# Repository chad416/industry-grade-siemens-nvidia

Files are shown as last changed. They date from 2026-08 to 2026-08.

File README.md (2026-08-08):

# FC01 Siemens/NVIDIA compact filling cell - Revision G

> FICTIONAL ENGINEERING PROJECT - NOT FOR CONSTRUCTION.

> CONCEPTUAL SAFETY ARCHITECTURE - REQUIRES PROJECT-SPECIFIC RISK ASSESSMENT, DESIGN, VERIFICATION AND VALIDATION BY A QUALIFIED MACHINERY-SAFETY ENGINEER. NO PERFORMANCE LEVEL, SIL, CATEGORY, CE/UKCA CONFORMITY OR REGULATORY COMPLIANCE IS CLAIMED.

Revision G is an evidence-driven execution release candidate. It preserves the verified Revision-F PLC/AI, QET and FreeCAD baseline while adding a disabled-by-default secure cloud foundation, exact Siemens native-access handoff, current NVIDIA execution pipeline, and commissioning-ready blank records.

Supported description: **cloud-ready and native-execution-ready with software-only NVIDIA pipeline validation**. Native TIA/WinCC/Startdrive/PLCSIM compile, representative data/model/target runtime, site electrical calculations, physical FAT/SAT/commissioning and qualified safety/electrical review remain open exactly as recorded in `00_project_control/revision_g_gate_status.md`.

No cloud resources were created. The PLC remains authoritative; NVIDIA is non-safety and any missing, stale, malformed, contradictory, uncertain or low-confidence result holds product and never commands hazardous outputs.

THE NVIDIA VISION SUBSYSTEM IS NON-SAFETY-RELATED AND MUST NOT BE USED AS THE SOLE MEANS OF PERSONNEL PROTECTION, SAFE STOP, GUARD MONITORING OR HAZARDOUS-MOTION CONTROL.

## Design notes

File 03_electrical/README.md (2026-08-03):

# Electrical design boundary - Revision E

> FICTIONAL ENGINEERING PROJECT — NOT FOR CONSTRUCTION

> CONCEPTUAL SAFETY ARCHITECTURE — REQUIRES PROJECT-SPECIFIC RISK ASSESSMENT, DESIGN, VERIFICATION AND VALIDATION BY A QUALIFIED MACHINERY-SAFETY ENGINEER. NO PERFORMANCE LEVEL, SIL, CATEGORY, CE CONFORMITY OR REGULATORY COMPLIANCE IS CLAIMED.

The controlled `revision_e` directory contains a genuinely authored, deterministic 26-folio QElectroTech 0.100 project reconciled at source level to the Revision-E device, I/O, terminal, cable and network schedules. Static verification covers folio structure, embedded symbols/conductors, unique PLC addresses, terminals and cables, scheduled device coverage and page-boundary constraints. The historical Revision-A project remains quarantined under `native_baseline` and is not the current schematic package.

The exact corrected QET SHA-256 was not reopened and exported after the final layout corrections. Native cross-reference resolution, final-hash PDF export and visual review of all 26 final folios therefore remain blocked. Site power/earthing/fault-current data, conductor sizing, protection/coordination, final vendor metadata and qualified construction review also remain open; no construction schematic claim is made.

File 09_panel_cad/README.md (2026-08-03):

# Panel CAD boundary - Revision E

> FICTIONAL ENGINEERING PROJECT — NOT FOR CONSTRUCTION

> CONCEPTUAL SAFETY ARCHITECTURE — REQUIRES PROJECT-SPECIFIC RISK ASSESSMENT, DESIGN, VERIFICATION AND VALIDATION BY A QUALIFIED MACHINERY-SAFETY ENGINEER. NO PERFORMANCE LEVEL, SIL, CATEGORY, CE CONFORMITY OR REGULATORY COMPLIANCE IS CLAIMED.

Revision E replaces the historical panel baseline as the current engineering representation. The controlled `revision_e` directory contains a genuine FreeCAD 1.1.3 selected-architecture assembly, native reopen/shape evidence, STEP and IGES reimport evidence, a structurally verified DXF mounting plate, schedules, dimensioned PDFs and four major rendered views. The historical Revision-A native files remain quarantined under `native_baseline` and are not evidence for Revision E.

The native verification record passes the dimensional and exchange checks stated there. It does not authorize fabrication. Final enclosure/IP selection, protective devices, terminal and relay families, NVIDIA carrier/cooling, vendor drilling and clearances, cable entry, duct fill, thermal rise, PE/bonding, EMC, site short-circuit data and qualified-human construction review remain open.

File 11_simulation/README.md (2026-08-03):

# Deterministic controls-process simulation

> FICTIONAL ENGINEERING PROJECT — NOT FOR CONSTRUCTION

This directory contains an independent, deterministic Python verification model for the compact two-nozzle filling cell. It is not a Siemens PLC application, TIA Portal compile, PLCSIM run, validated fluid model, or physical commissioning record.

## Model boundary

`filling_cell_simulator.py` couples four explicit time-stepped models:

- A controller state machine with command arbitration, first-out diagnostics, quality holding, reset/start separation, and restart inhibition.
- A plant with bottle transport, gate/clamp travel, common pump ramp, independent fail-closed valves, pulse totals, analog flow, and physical fill volume.
- A vision endpoint implementing monotonic inspection IDs, ready/busy/result timing, result correlation, heartbeat supervision, and semantic result validation.
- A capper endpoint implementing ready/request/busy/complete/fault timing.

The default integration step is 20 ms. The simulated controller observes only field and interface signals. Physical volume is hidden plant state used by the simulated vision endpoint, allowing correlated meter-calibration faults to produce independent underfill/overfill quality results.

## Deterministic failure behavior

All faults are injected into the evolving model, not returned from a result lookup. Timed/state-dependent injections cover bottle sensing, gate/clamp motion, VFDs, air/product utilities, pulse and analog disagreement, valve feedback, HMI communication, power, capper handshaking, PLC/vision heartbeats, result timeout, stale inspection ID, low confidence, and bottle quality failure.

The following invariants are checked at every step:

- No pump command outside `FILLING`.
- No valve command without the common pump command.
- No conveyor command while clamp/filling commands are active.
- No energized motion/fill command while simulated power is absent.
- Gate and clamp feedback remain proven through filling, settle, and inspection.
- Release occurs only after the capper complete handshake.
- Recovery/reset does not synthesize a start edge.

## Run and inspect

From the project root:

```powershell
python -m unittest discover -s 11_simulation/tests -v
python 11_simulation/run_scenarios.py
```

The scenario runner writes:

- `outputs/scenario_results.csv`: one evidence summary per canonical scenario.
- `outputs/traces/<scenario>.csv`: every sampled state, command, feedback, flow, interface, and handshake value.
- `outputs/run_metadata.json`: time-step configuration and an explicit `native_plcsim = NOT RUN` limitation.

Tests include deterministic repeatability, a 10/20/40/50 ms integration-step sweep, a supported 400/500/700 ml recipe-target sweep, transition-order checks, channel-independent shutoff, restart-inhibition checks, and negative PLC–vision protocol cases.

## Truthfulness limitation

Passing these tests demonstrates consistency of this independent model and its declared properties only. It does not prove that the Siemens sources compile, execute equivalently, meet PLC scan-time constraints, or pass PLCSIM/native hardware tests. Those gates remain separate and incomplete until the native Siemens toolchain is used.

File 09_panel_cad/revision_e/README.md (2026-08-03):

# FC01 Revision-E native panel CAD

> FICTIONAL ENGINEERING PROJECT — NOT FOR CONSTRUCTION

> CONCEPTUAL SAFETY ARCHITECTURE — REQUIRES PROJECT-SPECIFIC RISK ASSESSMENT, DESIGN, VERIFICATION AND VALIDATION BY A QUALIFIED MACHINERY-SAFETY ENGINEER. NO PERFORMANCE LEVEL, SIL, CATEGORY, CE CONFORMITY OR REGULATORY COMPLIANCE IS CLAIMED.

This directory is the genuine Revision-E FreeCAD package built and reopened with the controlled portable FreeCAD 1.1.3 command-line executable. It does not replace the quarantined Revision-A baseline in `../native_baseline`.

## Native boundary

- `FC01_control_panel_revision_e.FCStd` is the authoritative native model.
- STEP and IGES are full-panel physical-shape exports; non-physical clearance/segregation volumes are excluded. Independent native verification confirms STEP solid retention and a valid IGES face-compound/envelope; IGES solid retention is not claimed.
- `FC01_mounting_plate_revision_e.dxf` is a FreeCAD-exported local-coordinate mounting-plate outline and hole pattern.
- The placement and hole schedules distinguish selected manufacturer envelopes from provisional and architecture-only assumptions.
- The four PNGs are genuine FreeCAD GUI views rendered from the same physical geometry-definition source before a rejected post-save generic ZIP-repack attempt. A later controlled correction changed only the SW100/FW100/PC200 side-clearance metadata and its dimension-basis text; x/y/z/width/height/depth geometry and mounting holes did not change. The headless build requires the exact controlled PNG hashes and an invariant physical-geometry fingerprint. No final FCStd byte identity or second GUI reopen is claimed.
- General-arrangement and mounting-plate PDFs use those genuine views plus the final controlled geometry/schedules.

## Reproduction

Run the headless generator with isolated FreeCAD configuration files, then run the independent command-line verification in a second process:

```powershell
& $env:FC01_FREECAD_CMD -u $env:FC01_FREECAD_USER_CFG -s $env:FC01_FREECAD_SYSTEM_CFG scripts/freecad_revision_e.py
& $env:FC01_FREECAD_CMD -u $env:FC01_FREECAD_VERIFY_USER_CFG -s $env:FC01_FREECAD_VERIFY_SYSTEM_CFG scripts/verify_freecad_revision_e.py
```

The model is not a supplier-approved production model. The enclosure, protection, PSU, relay, terminal, duct, PE, Jetson carrier and cooling solution remain selection-dependent. Drive mounting coordinates require final confirmation against order-number CAx before drilling. Site supply, fault current, thermal environment, cable routes, maintenance access and qualified safety work remain external gates.

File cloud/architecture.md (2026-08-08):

# Revision G secure execution architecture

> FICTIONAL ENGINEERING PROJECT - NOT FOR CONSTRUCTION.

> CONCEPTUAL SAFETY ARCHITECTURE - REQUIRES PROJECT-SPECIFIC RISK ASSESSMENT, DESIGN, VERIFICATION AND VALIDATION BY A QUALIFIED MACHINERY-SAFETY ENGINEER. NO PERFORMANCE LEVEL, SIL, CATEGORY, CE/UKCA CONFORMITY OR REGULATORY COMPLIANCE IS CLAIMED.

Two laboratory environments are separated from each other and from any plant/OT network.

## Environment A - Siemens engineering

A Windows engineering host provides TIA Portal V20, STEP 7 Professional, WinCC Unified, Startdrive, PLCSIM/PLCSIM Advanced and TIA Openness. The primary recommendation is a dedicated always-on engineering workstation or a Siemens-supported VMware/Hyper-V environment. Ordinary Google Compute Engine is retained only as a technically plausible **unsupported laboratory candidate** pending written Siemens confirmation; Siemens V20 installation documentation explicitly names VMware vSphere 8+, Workstation/Player 17+ and Hyper-V Server 2019+, not GCE.

## Environment B - NVIDIA engineering

A separate Ubuntu 24.04 GPU host is provisioned only after approval. DeepStream 9.1 currently requires Ubuntu 24.04, driver 595.58.03, CUDA 13.2 and TensorRT 10.16.0.72 on dGPU. A G2/L4-class VM is a capacity and price candidate, not a selected or provisioned target. Jetson deployment must use the exact DeepStream/JetPack platform matrix and regenerate TensorRT engines for the intended runtime/hardware.

## Network and evidence flow

- Dedicated VPC/subnet; no VM external IP.
- IAP TCP forwarding is the only administrative ingress; firewall source is `35.235.240.0/20` to RDP/SSH tags.
- Cloud NAT provides bounded installation egress; egress firewall permits DNS, NTP and TLS only.
- Separate keyless service accounts; no project-owner grants.
- Versioned, uniform-access, public-access-prevented evidence bucket; no secrets in objects or Terraform state.
- Project audit logging plus optional CPU alert policies; notification-channel IDs remain operator-supplied variables.
- OPC UA and PLC traffic are laboratory-only. No direct conduit to a real plant is created.

Official sources:

- https://support.industry.siemens.com/cs/attachments/109963850/Install_STEP7_WinCC_V20_enUS.pdf
- https://cloud.google.com/iap/docs/tcp-forwarding-overview
- https://cloud.google.com/compute/docs/instances/schedule-instance-start-stop
- https://docs.nvidia.com/metropolis/deepstream/dev-guide/text/DS_Installation.html

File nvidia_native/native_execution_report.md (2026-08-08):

# NVIDIA native execution report

> FICTIONAL ENGINEERING PROJECT - NOT FOR CONSTRUCTION.

> CONCEPTUAL SAFETY ARCHITECTURE - REQUIRES PROJECT-SPECIFIC RISK ASSESSMENT, DESIGN, VERIFICATION AND VALIDATION BY A QUALIFIED MACHINERY-SAFETY ENGINEER. NO PERFORMANCE LEVEL, SIL, CATEGORY, CE/UKCA CONFORMITY OR REGULATORY COMPLIANCE IS CLAIMED.

The local RTX 5060 driver query executed successfully. CUDA toolkit (`nvcc`), Docker, NVIDIA Container Toolkit, TAO, TensorRT, DeepStream, OpenUSD and Omniverse were not found. No cloud GPU resource exists. The deterministic synthetic smoke exercises the existing acquisition/preprocess/mock boundary and proves the mock backend is refused by `VisionService`; it does not decode representative images, train a model, create ONNX/TensorRT artifacts, measure latency or validate production OPC UA.

Current official planning baseline is DeepStream 9.1 on Ubuntu 24.04; dGPU prerequisites include driver 595.58.03, CUDA 13.2 and TensorRT 10.16.0.72. TAO-trained engines must be regenerated for their exact TensorRT/CUDA/hardware environment. Sources: https://docs.nvidia.com/metropolis/deepstream/dev-guide/text/DS_Installation.html and https://docs.nvidia.com/tao/tao-toolkit/latest/text/ds_tao/deepstream_tao_integration.html.

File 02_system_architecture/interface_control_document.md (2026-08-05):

# PLC-NVIDIA interface control document - Revision F

> FICTIONAL ENGINEERING PROJECT — NOT FOR CONSTRUCTION

> CONCEPTUAL SAFETY ARCHITECTURE — REQUIRES PROJECT-SPECIFIC RISK ASSESSMENT, DESIGN, VERIFICATION AND VALIDATION BY A QUALIFIED MACHINERY-SAFETY ENGINEER. NO PERFORMANCE LEVEL, SIL, CATEGORY, CE CONFORMITY OR REGULATORY COMPLIANCE IS CLAIMED.

## Ownership and transaction

The PLC freezes session epoch, inspection ID, recipe, bottle count, fill target and expected model/dataset/calibration identities before raising the level-held request. The edge validates the complete snapshot, publishes capture acknowledgement and processing state, then writes one complete immutable result before `RESULT_VALID`. The PLC accepts only the exact current session/ID, coherent capture acknowledgement, healthy service/camera/model, approved identities, allowed disposition/reasons/confidence and PLC-derived age. Exact acknowledgement clears the result but never authorizes transfer.

The 47 typed nodes, OPC UA types, owner, update rule and invalid action are controlled in `10_schedules/nvidia_interface_tags.csv`. OPC UA typed scalars abstract byte order; no application byte swapping is permitted. Disconnect, restart, recipe change, clock jump, stale/duplicate/future ID, malformed/contradictory payload, low confidence, fault, queue saturation or maintenance state fails closed.

THE NVIDIA VISION SUBSYSTEM IS NON-SAFETY-RELATED AND MUST NOT BE USED AS THE SOLE MEANS OF PERSONNEL PROTECTION, SAFE STOP, GUARD MONITORING OR HAZARDOUS-MOTION CONTROL.

Local encrypted asyncua tests are not production S7/Jetson/PKI evidence. Native TIA/WinCC compilation and target endpoint commissioning remain blocked.

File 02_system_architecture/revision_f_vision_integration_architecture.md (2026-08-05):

# Revision-F NVIDIA vision integration architecture

> FICTIONAL ENGINEERING PROJECT - NOT FOR CONSTRUCTION

> CONCEPTUAL SAFETY ARCHITECTURE - REQUIRES PROJECT-SPECIFIC RISK ASSESSMENT, DESIGN, VERIFICATION AND VALIDATION BY A QUALIFIED MACHINERY-SAFETY ENGINEER. NO PERFORMANCE LEVEL, SIL, CATEGORY, CE CONFORMITY OR REGULATORY COMPLIANCE IS CLAIMED.

> THE NVIDIA VISION SUBSYSTEM IS NON-SAFETY-RELATED AND MUST NOT BE USED AS THE SOLE MEANS OF PERSONNEL PROTECTION, SAFE STOP, GUARD MONITORING OR HAZARDOUS-MOTION CONTROL.

## Functional boundary

The Siemens S7-1500 remains the sole owner of modes, sequence state, interlocks, timeouts, actuator and drive requests, restart behavior, product disposition and transfer permission. Process flow and level instrumentation remains the deterministic fill measurement. Vision supplies an independent quality observation only: bottle presence/alignment, visible fill band, underfill/overfill indication, severe foam or abnormal appearance and visible spill/leak where optics permit.

The provisional model approach is hybrid rather than generic object detection alone:

1. deterministic geometry and calibration locate the carrier, bottle ROIs and fill-reference band;
2. segmentation or calibrated level-line estimation measures visible liquid/foam regions;
3. detection localizes bottle/nozzle/spill anomalies where a global classifier would obscure cause;
4. a learned classifier or Visual ChangeNet-style comparison may provide an additional anomaly score against approved reference images;
5. the edge policy combines the observations conservatively and publishes PASS only when every required channel is present, coherent and above validated thresholds.

This approach is provisional until transparent-container feasibility, glare, liquid appearance, production variation and reject economics are measured.

## One-camera versus two-camera decision

| Criterion | One camera | Two cameras |
|---|---|---|
| Initial cost and integration | Lower | Higher |
| Two-bottle coverage | Possible with wider field and lower pixels/mm | Dedicated or overlapping views improve per-bottle resolution |
| Occlusion and parallax | Higher risk | Lower risk when views are selected independently |
| Glare management | One illumination/view compromise | More options for cross-polarized/backlight and oblique views |
| Calibration/maintenance | Simpler | Additional calibration, synchronization and spares |
| Current disposition | Provisional baseline for feasibility trial | Contingency if pixel, glare or occlusion margin fails |

No camera count, sensor, lens or enclosure is released for procurement. The optical feasibility trial must calculate field of view and pixels per smallest decision feature, then demonstrate focus, distortion, exposure and motion-blur margin at maximum line speed.

## Trigger and timing lifecycle

The PLC freezes recipe, carrier position, expected bottle count, target fill band, expected model/dataset/calibration identities and the nonzero session/inspection identity before asserting a level-held trigger. The edge publishes capture acknowledgement only after the correct request identity is accepted and an image is bound to it. Processing state then advances through acquired, preprocessing, inference and post-processing. Result payload fields are written first and `RESULT_VALID` last. The immutable publication remains until exact PLC acknowledgement.

Any timeout, heartbeat loss/regression, stale/duplicate/future identity, recipe mutation, clock discontinuity, camera/model/configuration fault, queue saturation, malformed or contradictory payload, insufficient confidence or expired result prevents PASS. Recovery never restarts the machine automatically.

## Failure containment

- The edge has no writable PLC node that energizes motion or bypasses a permissive.
- The PLC decommands pump and fill valves independently of vision communications.
- Offline buffering of inspection decisions is prohibited. At most one current immutable unacknowledged publication may be restored after restart.
- Log-storage failure is a blocking diagnostic because required traceability cannot be completed.
- Maintenance bypass is a request for controlled operator disposition, not an automatic quality acceptance.
- A recipe or calibration change invalidates an active transaction and requires a new inspection.

## Network and trust boundary

`-PC200` resides in VLAN 20 and acts as the OPC UA client to the PLC server in VLAN 10 through the deny-by-default `-FW100` boundary. Only TCP 4840 for the named application identities and approved namespace is permitted. Application and user certificates, pinned server identity, trust/revocation stores, least-privilege node rights, authenticated time and centralized security logging are required. Image transfer is not permitted across the PLC boundary.

## Time and records

The PLC correlation identity is authoritative even if clocks disagree. UTC capture and inference timestamps support diagnostics and result-age checks but never replace session/inspection correlation. The site must provide an authenticated NTP/PTP hierarchy, maximum permitted clock step, resynchronization rule and log-retention owner. Raw images are not retained by default; approved fault/challenge samples may be retained under a documented privacy, capacity and deletion policy.

## Maintainability

Camera, lens, lighting, carrier, edge image, model bundle, dataset baseline and calibration each have independent identifiers and hashes. Replacement requires mechanical datum restoration, focus/aperture lock, exposure/illumination verification, calibration challenge images, secure OPC UA smoke tests and a bounded rollback. A golden configuration alone is not proof that optics or process conditions remain acceptable.

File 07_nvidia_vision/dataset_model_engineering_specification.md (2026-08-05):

# FC01 dataset and model engineering specification

> FICTIONAL ENGINEERING PROJECT — NOT FOR CONSTRUCTION

> CONCEPTUAL SAFETY ARCHITECTURE — REQUIRES PROJECT-SPECIFIC RISK ASSESSMENT, DESIGN, VERIFICATION AND VALIDATION BY A QUALIFIED MACHINERY-SAFETY ENGINEER. NO PERFORMANCE LEVEL, SIL, CATEGORY, CE CONFORMITY OR REGULATORY COMPLIANCE IS CLAIMED.

No representative dataset, trained model, accuracy result or production threshold is delivered. Synthetic data is permitted only for pipeline tests and is never production validation evidence.

## Inspection strategy

The provisional architecture is hybrid: calibrated deterministic geometry estimates visible fill line and alignment inside verified bottle ROIs; a detector/segmenter localizes bottles, liquid/foam and visible spill evidence. This is more defensible than a single global pass/fail classifier because it preserves interpretable geometry and defect localization. Transparent bottles, specular glare and foam require polarized/diffuse lighting trials. Cap inspection is a downstream extension, not part of the released filling decision.

## Required collection matrix

Collect by independent production lot and acquisition session across every bottle SKU, nominal/under/over fill, liquid color/transmission/viscosity, foam severity, bottle lot, lighting drift, camera/lens replacement, focus and exposure limits, background, nozzle position, misalignment, occlusion, contamination, drip/spill, empty carrier, label state and environmental condition. Record true fill reference by a traceable independent method. Include clean negatives and hard negatives. Do not manufacture class balance by duplicating adjacent video frames.

## Storage and annotation

The dataset root contains `images/`, `annotations/`, `manifests/`, `calibration/`, `collection_records/` and `reviews/`. `dataset_manifest.csv` uses the exact v2 header enforced by `dataset_tool.py`; all paths are dataset-root-relative and every image/annotation has SHA-256. Production lot plus acquisition session is the leakage-control group. Real/synthetic provenance is mandatory.

Classes: bottle; bottle misalignment; visible bottle damage; liquid region; foam; drip; spill. Each bottle has a polygon/bounding box and two calibrated fill-line endpoints where visible. Occluded or ambiguous samples use `unknown`, never a forced pass/fail label. Two reviewers independently review release test/challenge data; disagreements are adjudicated by an authorized domain reviewer and the original labels are retained in history.

`dataset_tool.py validate` verifies schema, paths, hashes, exact duplicates, review state and split leakage. `split` makes a deterministic group-level assignment. Exact SHA duplicates are implemented; near-duplicate image embedding/perceptual review remains a required external extension once images exist.

## Evaluation and promotion

Freeze train/validation/test manifests before threshold selection. Select thresholds on validation only; run the held-out test once for the candidate. Report per-class precision, recall and F1, confusion matrices, under/overfill error against the physical reference, false accept and false reject by condition, calibration error, robustness slices and confidence coverage. `dataset_tool.py evaluate` computes binary confusion/false-accept/false-reject values from supplied predictions; unit-test rows are not performance evidence.

Model promotion requires: controlled model/framework/container/config/dataset/calibration hashes; independent test and challenge-set review; target camera-to-PLC latency distribution; thermal and reconnect soak; failure-mode test; cybersecurity review; named approval authority; rollback rehearsal; and PLC/HMI acceptance criteria. A signed bundle includes model, input/output tensor contract, preprocessing, class map, thresholds, dataset ID, calibration compatibility, SBOM and model card. Rollback disables production, restores the prior complete bundle, verifies hashes, repeats negative tests and never automatically restarts the machine.

## External closure criteria

Provide representative real images and traceable fill references; select camera/lens/light and target edge; approve privacy/retention; run collection and independent annotation; install a supported training/runtime stack; execute training/evaluation; and retain immutable logs/hashes. Only those results may populate `model_card.md` and `evaluation_report.md`.

THE NVIDIA VISION SUBSYSTEM IS NON-SAFETY-RELATED AND MUST NOT BE USED AS THE SOLE MEANS OF PERSONNEL PROTECTION, SAFE STOP, GUARD MONITORING OR HAZARDOUS-MOTION CONTROL.

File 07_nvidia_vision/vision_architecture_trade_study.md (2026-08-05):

# FC01 vision architecture and provisional hardware trade study

> FICTIONAL ENGINEERING PROJECT — NOT FOR CONSTRUCTION

> CONCEPTUAL SAFETY ARCHITECTURE — REQUIRES PROJECT-SPECIFIC RISK ASSESSMENT, DESIGN, VERIFICATION AND VALIDATION BY A QUALIFIED MACHINERY-SAFETY ENGINEER. NO PERFORMANCE LEVEL, SIL, CATEGORY, CE CONFORMITY OR REGULATORY COMPLIANCE IS CLAIMED.

No camera, lens, lighting or edge computer is selected. Dimensions, watts and thermal values remain controlled input fields until throughput, bottle envelope, environment and vendor data exist.

## Inspection requirement

The primary station verifies two-bottle presence/alignment, visible fill level, underfill/overfill, severe foam and visible spill/leak evidence where geometry permits. Flow and level instrumentation remain the deterministic filling-process measurements. Vision is an independent non-safety quality check. Cap inspection is downstream scope.

## One versus two cameras

| Criterion | One paired-bottle camera | Two bottle cameras |
|---|---|---|
| Cost, ports, power, calibration | Lower | Higher |
| Pixels per bottle and independent adjustment | Lower/shared | Higher/independent |
| Occlusion and nozzle accommodation | Harder | Easier |
| Common-cause camera failure | Both observations lost | Partial diagnostic availability, but cell still HOLDs unless the approved recipe permits otherwise |
| Maintenance | One spare/alignment | More spares and cross-camera consistency |

The provisional baseline is one fixed global-shutter color camera with a paired-bottle field of view, backlight for liquid boundary and separately controlled diffuse front light for gross visible defects/spill. Select two cameras if the measured pixel density, occlusion or depth-of-field trial fails. This decision cannot close without bottle/nozzle envelope and physical images.

## Optical calculations and timing

Required field width is `2 × maximum bottle width + centre spacing allowance + setup margins`, then at least 10% framing reserve. Pixel density is `horizontal pixels / calibrated field width`; validation must establish the minimum pixels needed for fill tolerance and defect dimensions. Thin-lens first estimate is `f ≈ sensor width × working distance / field width`; confirm with manufacturer lens data and working-distance trial.

The PLC freezes the indexed carrier, allows drip/foam settle, and raises the inspection request. Capture acknowledgement must match the request ID before processing. Exposure must limit blur to the validated pixel budget: `blur_px = image_velocity_mm_s × exposure_s × pixel_density_px_mm`. Record trigger jitter, exposure start, capture, processing and publication timing. Edge UTC timestamps are diagnostic only; PLC result-age acceptance uses the PLC monotonic/receipt clock.

## Edge platform criteria

| Criterion | Jetson Orin industrial module/carrier | Industrial x86 with NVIDIA GPU |
|---|---|---|
| Compactness/power | Usually favorable | Usually larger/higher |
| Service ecosystem | Embedded Linux/vendor carrier specific | Conventional industrial-PC service |
| GPU/runtime portability | JetPack/DeepStream constrained | Broader discrete-GPU options |
| Expansion/storage | Carrier dependent | Often broader |
| Lifecycle/environment | Requires selected industrial carrier evidence | Requires selected industrial PC/GPU evidence |

Selection requires measured camera rate, model memory/compute, worst-case latency, ambient/enclosure temperature, ingress/vibration, supply, lifecycle, cybersecurity support and spares strategy. Reserve separately protected power, service isolation, Ethernet switch port, grounded metal mounting, shield termination, cable entries, ventilation/heat allowance and maintenance clearance. The current panel allocation is provisional; no wattage or clearance is released from this trade study.

Network design uses the managed OT switch, one edge-to-PLC OPC UA conduit and separately governed maintenance access. Time uses the site NTP/PTP hierarchy with offset alarms; transaction correctness never depends solely on wall-clock agreement. Configuration/model/calibration are immutable bundles with hashes. Replacement requires identical or reviewed hardware, restored trust/config, new optical calibration where the imaging chain changes, negative tests and no automatic machine restart.

THE NVIDIA VISION SUBSYSTEM IS NON-SAFETY-RELATED AND MUST NOT BE USED AS THE SOLE MEANS OF PERSONNEL PROTECTION, SAFE STOP, GUARD MONITORING OR HAZARDOUS-MOTION CONTROL.

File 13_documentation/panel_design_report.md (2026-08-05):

# Panel design report - Revision F

> FICTIONAL ENGINEERING PROJECT — NOT FOR CONSTRUCTION

> CONCEPTUAL SAFETY ARCHITECTURE — REQUIRES PROJECT-SPECIFIC RISK ASSESSMENT, DESIGN, VERIFICATION AND VALIDATION BY A QUALIFIED MACHINERY-SAFETY ENGINEER. NO PERFORMANCE LEVEL, SIL, CATEGORY, CE CONFORMITY OR REGULATORY COMPLIANCE IS CLAIMED.

## Native layout basis

The inherited Revision-E FreeCAD 1.1.3 selected-architecture assembly remains the current natively reopened CAD authority: 800 x 800 x 300 mm provisional enclosure, drilled mounting plate, separated drive/power/control/network zones, Siemens PLC/I/O/HMI/drive envelopes and a provisional NVIDIA edge-compute envelope.

## Revision-F electrical delta boundary

`03_electrical/revision_f_nvidia_electrical_delta.md` reserves provisional protected edge, camera, lighting and service branches plus unique C200-C206 power/network cable identifiers. It is a standalone delta and has not been incorporated into the native FCStd, QET, canonical BOM, terminal/cable/P2P or panel-placement authorities. Gate 14 therefore remains PARTIAL.

## Open construction inputs

Selected carrier/camera/light hardware, enclosure series/IP, branch protection, cable entry, duct fill, thermal rise, PE/bonding, EMC, fault-current/SCCR data, vendor drilling, site clearances and qualified-human review remain open.

THE NVIDIA VISION SUBSYSTEM IS NON-SAFETY-RELATED AND MUST NOT BE USED AS THE SOLE MEANS OF PERSONNEL PROTECTION, SAFE STOP, GUARD MONITORING OR HAZARDOUS-MOTION CONTROL.

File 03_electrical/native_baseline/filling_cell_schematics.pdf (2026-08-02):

0 | 1 | 2 | 3 | 4 | 5 | 6 | 7 | 8 | 9 | 10 | 11 | 12 | 13 | 14

A

B

C

D

E

F

Author : Principal electrical engineer - concept | Cover, metadata, revision history | File : filling_cell.qet
Date : | | Folio : 1/24

# E-01 COVER, METADATA, REVISION HISTORY

# FICTIONAL CONCEPT DESIGN - NOT FOR CONSTRUCTION

# Compact Automated Two-Nozzle Bottle-Filling Cell

# Electrical schematic set | Revision A | 24 folios

# FICTIONAL CONCEPT DESIGN - NOT FOR CONSTRUCTION

CONCEPTUAL SAFETY ARCHITECTURE - REQUIRES REVIEW, RISK ASSESSMENT, VERIFICATION AND VALIDATION BY A QUALIFIED MACHINERY-SAFETY ENGINEER. NOPERFORMANCE LEVEL, SIL, CATEGORY OR REGULATORY COMPLIANCE IS CLAIMED.

# 400/230 VAC 3P+N+PE, 50 Hz, TN-S assumed | 24 VDC PELV | Indoor IP54 concept

A

B

C

D

E

F

# Drawing index

# E-02 DRAWING INDEX

# FICTIONAL CONCEPT DESIGN - NOT FOR CONSTRUCTION

# E-01 Cover, metadata, revision history

# E-02 Drawing index

# E-03 Design basis, legends, reference designations

# E-04 Functional overview and operating-state block diagram

# E-05 Single-line power distribution

# E-06 Incoming isolation and branch protection

# E-07 24 VDC PELV supply and protected distribution

# E-08 Conceptual safety architecture

# E-09 PLC, HMI, Ethernet and controller power

# E-10 PLC digital inputs - module DI001

# E-11 PLC digital inputs - module DI002

# E-12 PLC digital inputs - module DI003 and spares

# E-13 PLC digital outputs - module DO001

# E-14 PLC digital outputs - module DO002 and spares

# E-15 PLC analog inputs and outputs

# E-16 Conveyor VFD control and power wiring

# E-17 Conveyor motor, PE and shield termination

# E-18 Dosing-pump VFD and motor interface

# E-19 Two-channel filling valves and flow instrumentation

# E-20 Bottle, gate, clamp, air and product sensors

# E-21 HMI, stack light and capping-station interface

# E-22 Terminal-strip plan and field connections

# E-23 Cable overview, EMC and segregation notes

# E-24 Spare capacity, general notes and commissioning prerequisites

A

B

C

D

E

F

# Design basis, legends, reference designations

# E-03 DESIGN BASIS, LEGENDS, REFERENCE DESIGNATIONS

# FICTIONAL CONCEPT DESIGN - NOT FOR CONSTRUCTION

CONCEPTUALSAFETYARCHITECTURE- REQUIRESREVIEW,RISKASSESSMENT,
VERIFICATION AND VALIDATION BYAQUALIFIED MACHINERY-SAFETYENGINEER. NOPERFORMANCELEVEL,SIL,CATEGORYOR REGULATORYCOMPLIANCEISCLAIMED.
REFERENCE DESIGNATION: =FC01+LOCATION-TAG | CP01 panel | FD01 field | OP01 operator | IF01 capping

SUPPLY BASIS: 400/230 VAC, 3P+N+PE, 50 Hz, TN-S assumed. CONTROL: 24 VDC PELV.

PNP ordinary sensors. Analog: isolated 4-20 mA; provisional raw 5530-27648. Field devices terminate at identified X strips.

PROTECTION, CONDUCTOR SIZING, VOLTAGE DROP, FAULT WITHSTAND AND THERMAL RESULTSARE PRELIMINARY.

Wire IDs are unique physical segments. Cable/core and terminal references appear beside signal blocks; schedules are authoritative.

No PL, SIL, category, CE, UL, SCCR or regulatory compliance is claimed.

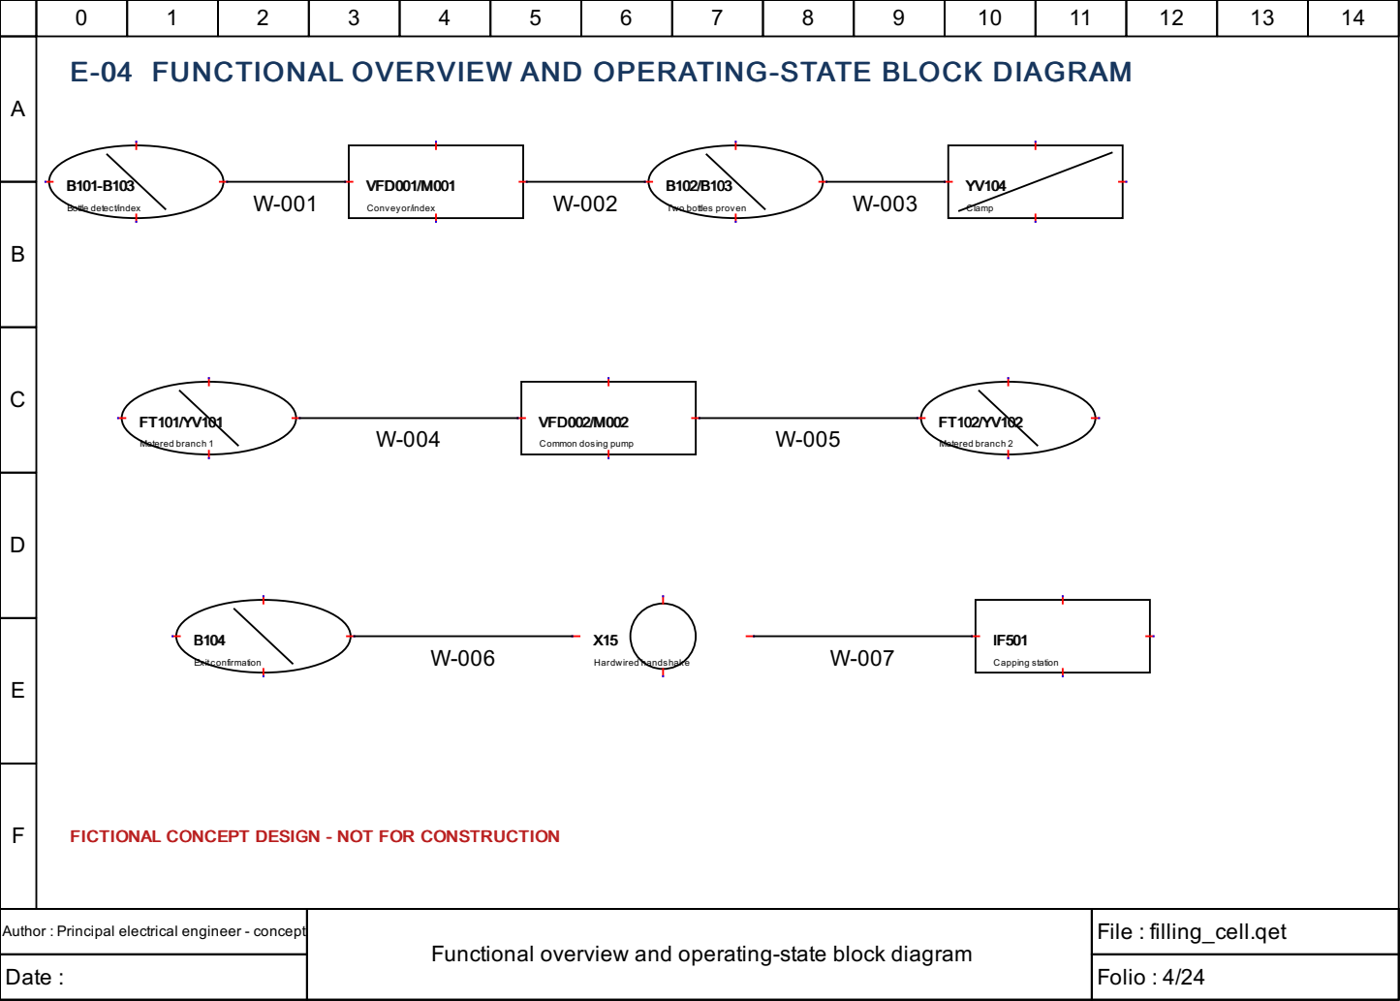
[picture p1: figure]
Bottle detect/index; VFD001/M001; Conveyor/index; Two bottles proven; Clamp; Metered branch 1; VFD002/M002; Common dosing pump; Metered branch 2; Exitconfirmation; Hardwired handshake; Capping station

# Functional overview and operating-state block diagram

# E-04 FUNCTIONAL OVERVIEW AND OPERATING-STATE BLOCK DIAGRAM

# FICTIONAL CONCEPT DESIGN - NOT FOR CONSTRUCTION

A

B

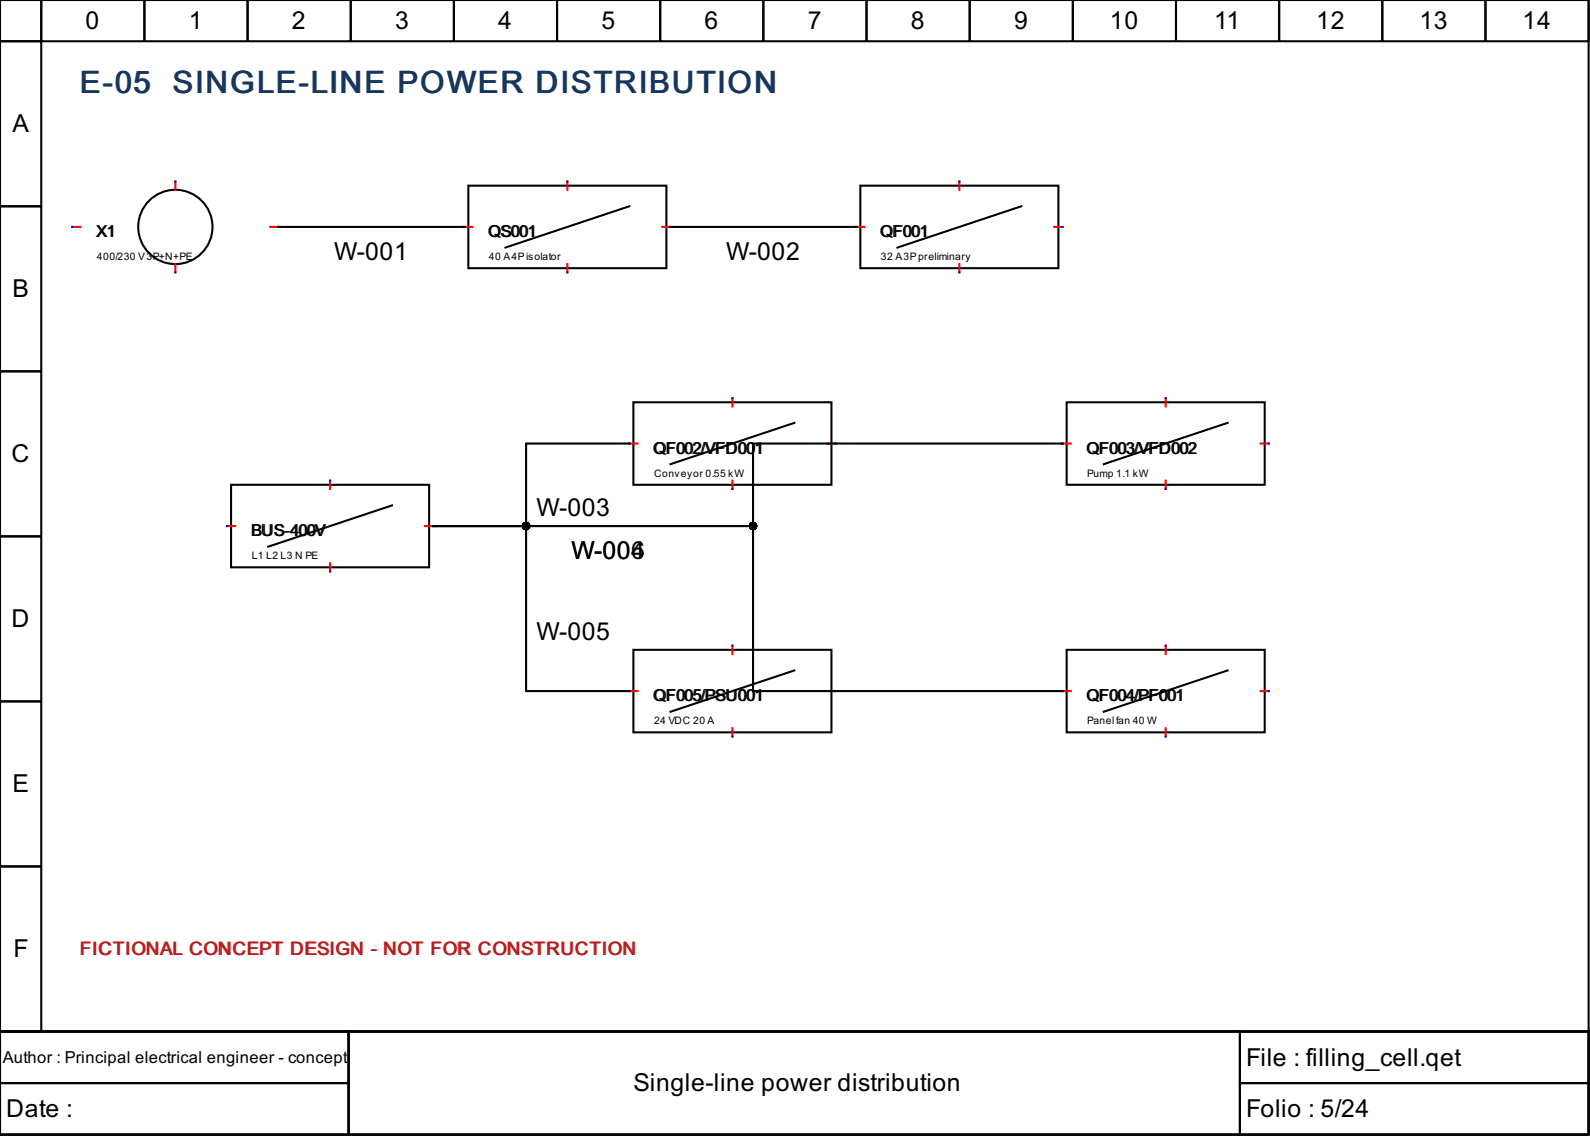
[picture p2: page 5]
40 A4Pisolator; 32 A3Ppreliminary; BUS-400V; QF002/VFD001; Conveyor 0.55 kW; QF003/VFD002; Pump 1.1 kW; QF005/PSU001; 24 VDC 20 A; Panel fan 40 W

E-05 SINGLE-LINE POWER DISTRIBUTION

FICTIONAL CONCEPT DESIGN - NOT FOR CONSTRUCTION

Single-line power distribution

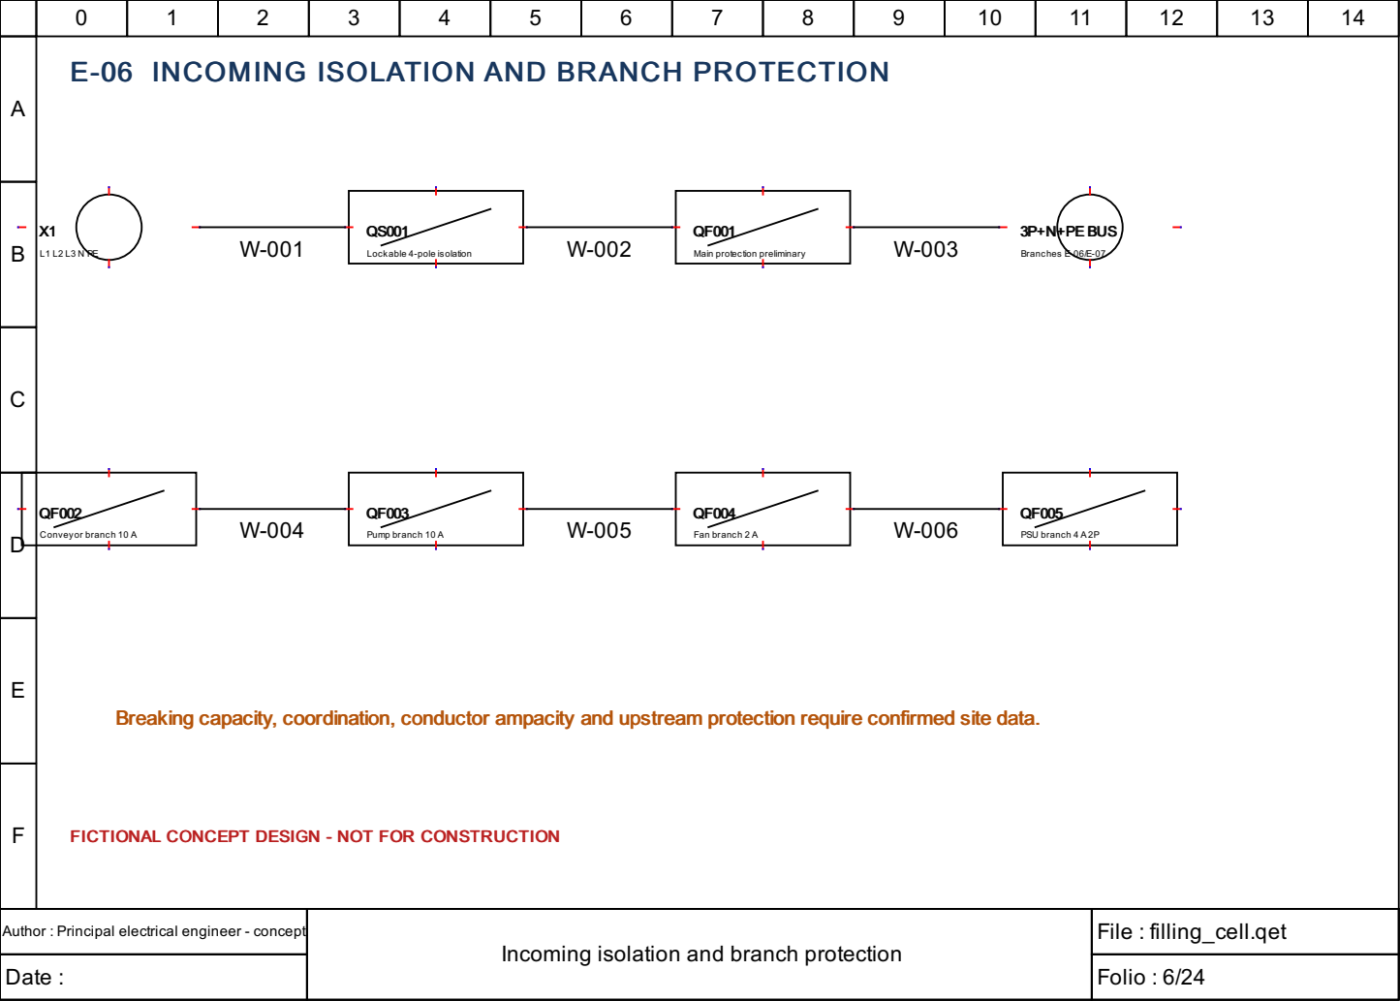
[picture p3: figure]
Lockable 4-pole isolation; Main protection preliminary; 3P+N+PE BUS; Branches E-06/E-07; Conveyor branch 10 A; Pump branch 10 A; Fan branch 2 A; PSU branch 4 A2P

# Incoming isolation and branch protection

# E-06 INCOMING ISOLATION AND BRANCH PROTECTION

# FICTIONAL CONCEPT DESIGN - NOT FOR CONSTRUCTION

Breaking capacity, coordination, conductor ampacity and upstream protection require confirmed site data.

A

B

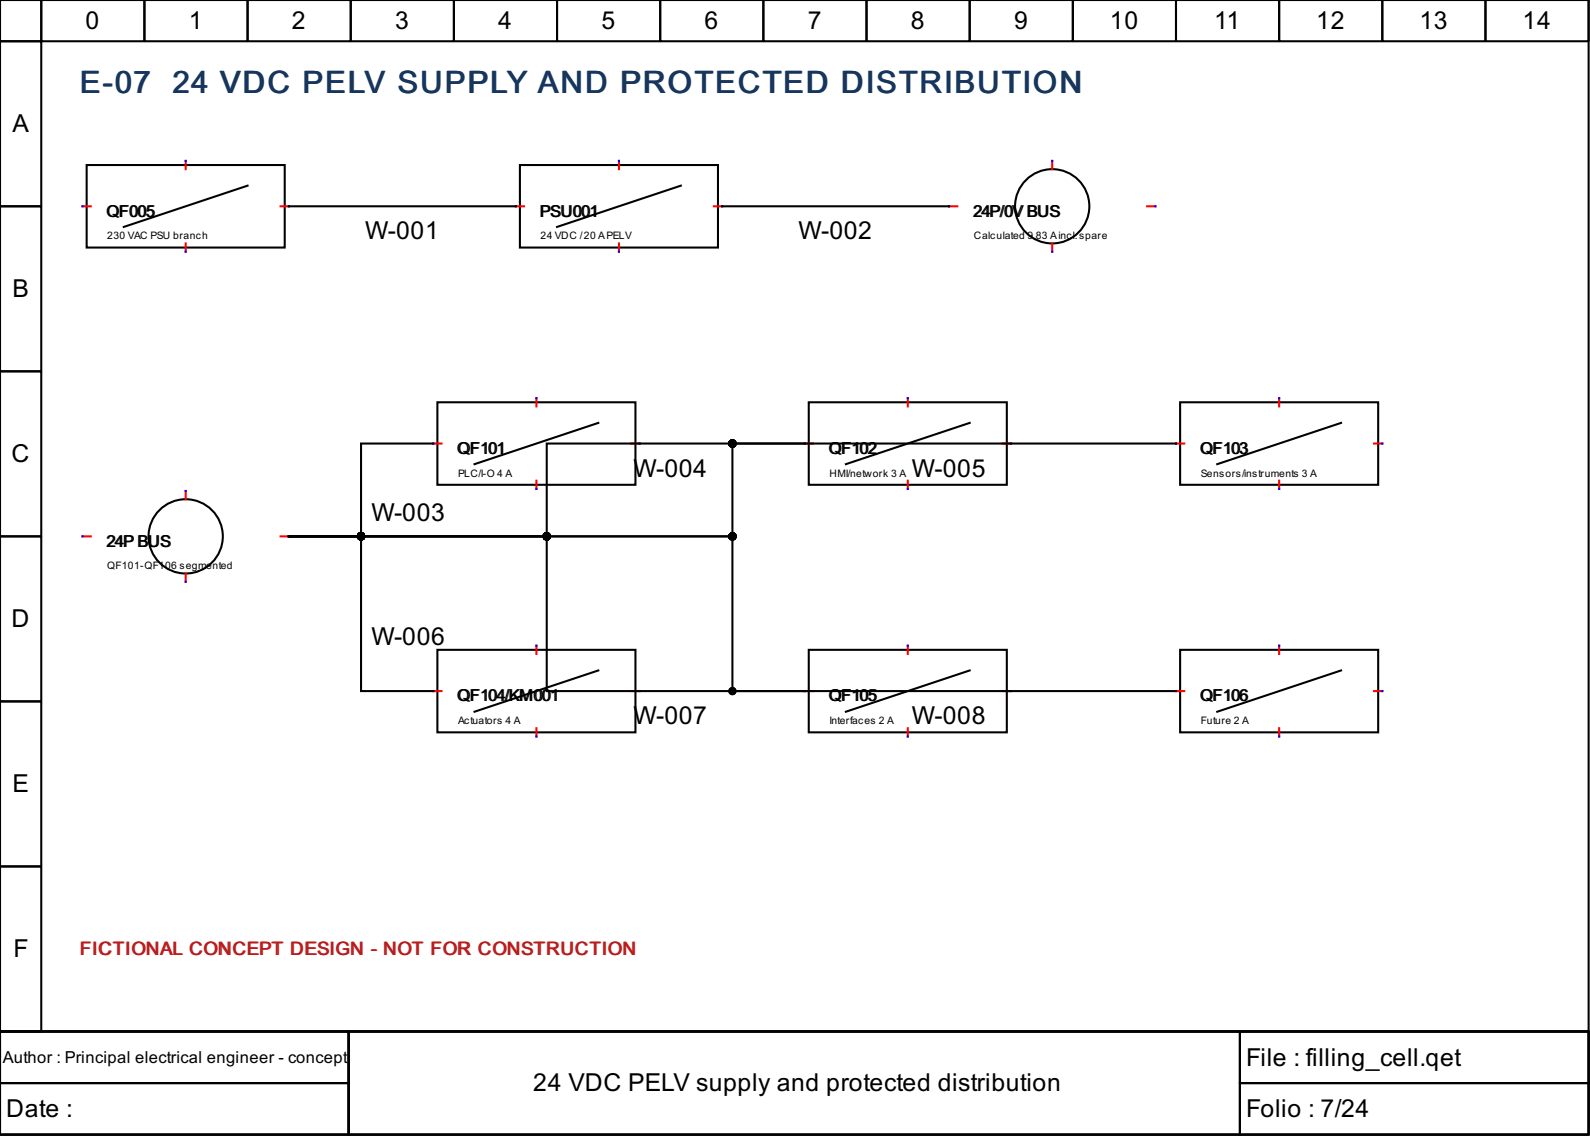
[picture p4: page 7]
PSU001; 24 VDC /20 APELV; 24P/0V BUS; 24P BUS; QF101-QF106 segmented; PLC/I-O 4 A; HMI/network 3 A; Sensors/instruments 3 A; Actuators 4 A; Interfaces 2 A; Future 2 A

E-07 24 VDC PELV SUPPLY AND PROTECTED DISTRIBUTION

230 VAC PSU branch

Calculated 9.83 Aincl.spare

FICTIONAL CONCEPT DESIGN - NOT FOR CONSTRUCTION

24 VDC PELV supply and protected distribution

A

B

C

D

E

F

# Conceptual safety architecture

# E-08 CONCEPTUAL SAFETY ARCHITECTURE

# FICTIONAL CONCEPT DESIGN - NOT FOR CONSTRUCTION

CONCEPTUALSAFETYARCHITECTURE- REQUIRESREVIEW,RISKASSESSMENT,
VERIFICATION AND VALIDATION BYAQUALIFIED MACHINERY-SAFETYENGINEER. NOPERFORMANCELEVEL,SIL,CATEGORYOR REGULATORYCOMPLIANCEISCLAIMED.

S001

Dual-channel E-stop

S007

Dual-channel guard

## KSR001

Safety relay CONCEPT

## STO A/B

VFD001 + VFD002

S002

Manual safety reset

KM001

Actuator bus contactor

## EDM

Feedback monitoring

Standard PLC monitors status only. Restoration never starts motion. Required functions/performance are not determined here.

W-001 | W-002 | W-003
W-004 | W-005

A

B

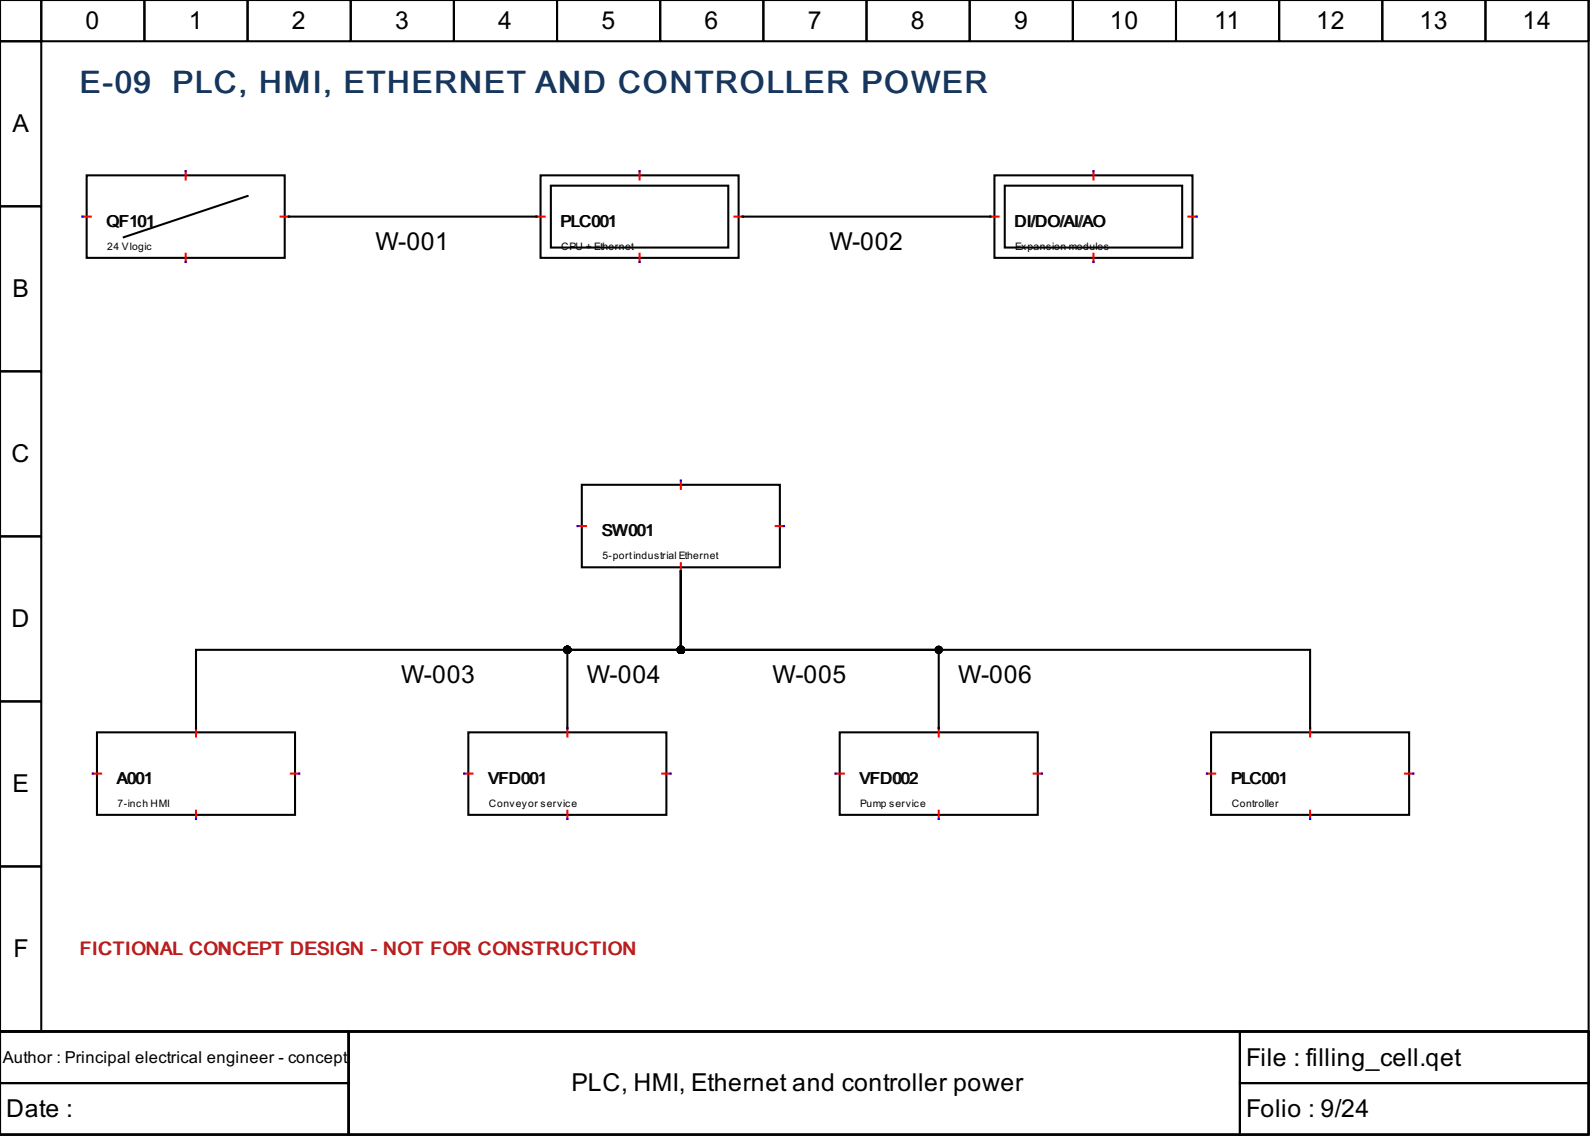
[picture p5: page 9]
24 Vlogic; PLC001; CPU + Ethernet; Expansion modules; 5-portindustrial Ethernet; 7-inch HMI; VFD001; Conveyor service; VFD002; Pump service; Controller

E-09 PLC, HMI, ETHERNET AND CONTROLLER POWER

FICTIONAL CONCEPT DESIGN - NOT FOR CONSTRUCTION

PLC, HMI, Ethernet and controller power

A

B

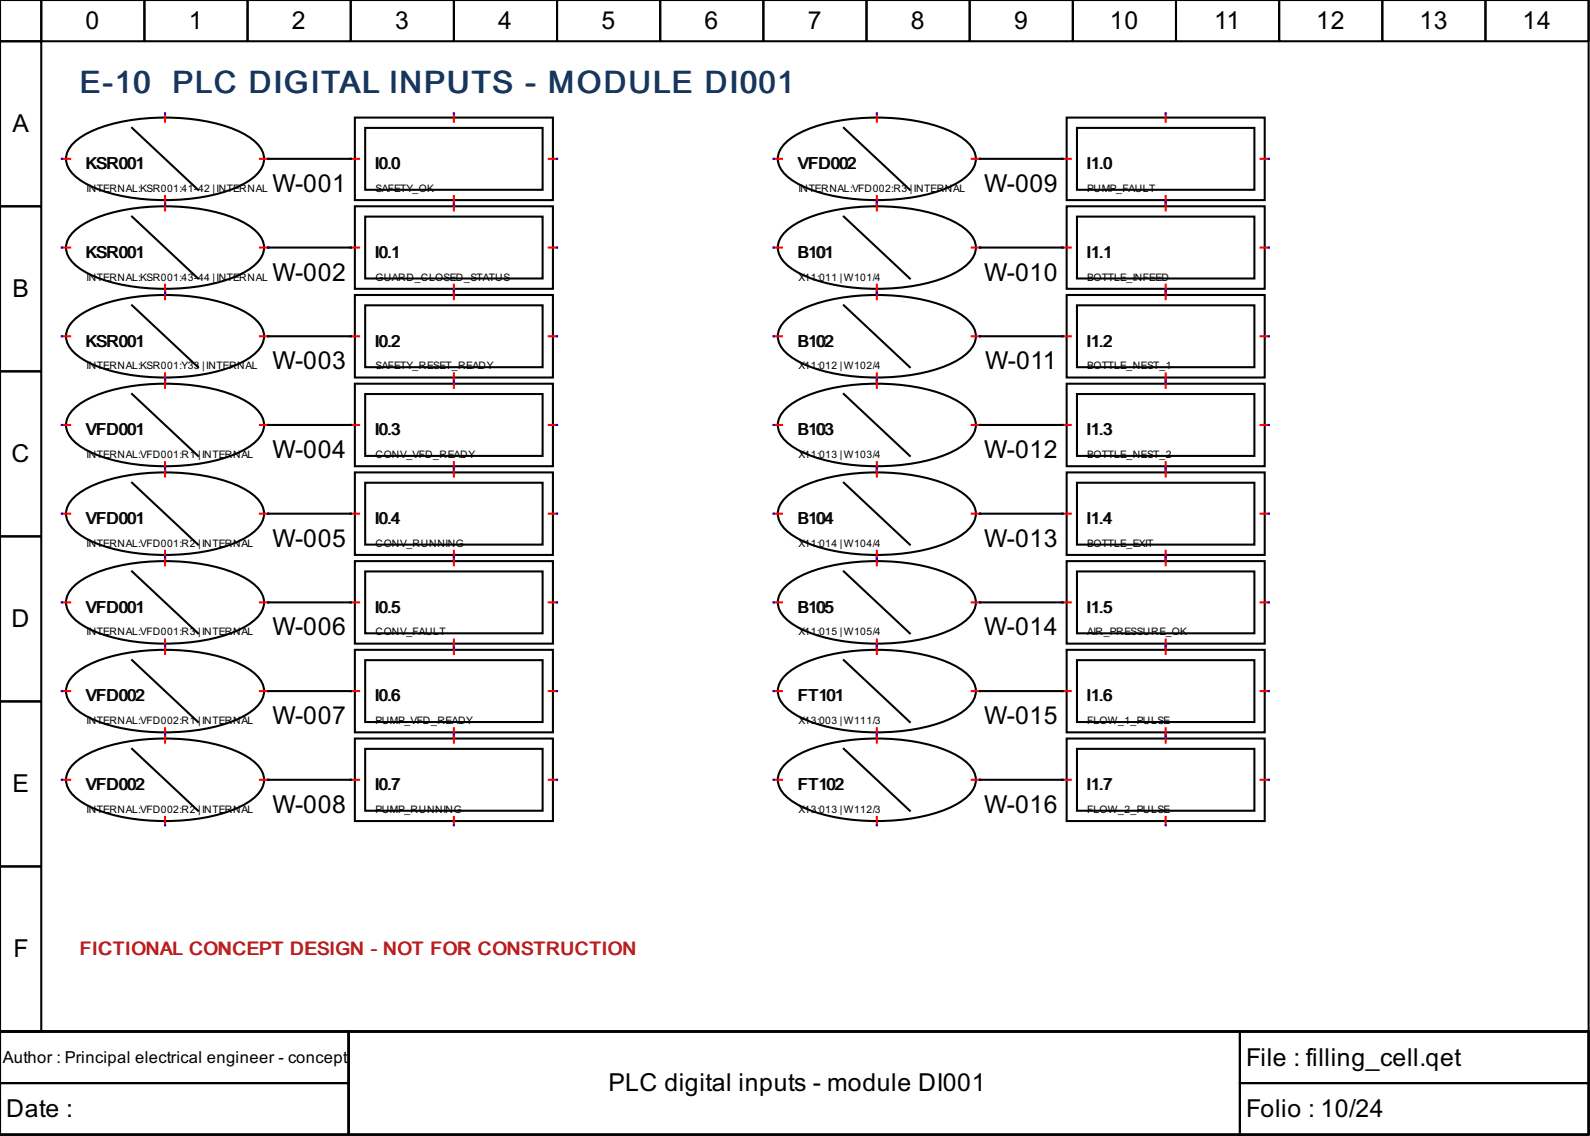
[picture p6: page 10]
KSR001; INTERNAL:KSR001:41-42 | INTERNAL; SAFETY_OK; INTERNAL:KSR001:43-44 | INTERNAL; GUARD_CLOSED_STATUS; INTERNAL:KSR001:Y33 | INTERNAL; SAFETY_RESET_READY; VFD001; INTERNAL:VFD001:R1 | INTERNAL; CONV_VFD_READY; INTERNAL:VFD001:R2 | INTERNAL; CONV_RUNNING; INTERNAL:VFD001:R3 | INTERNAL; CONV_FAULT; VFD002; INTERNAL:VFD002:R1 | INTERNAL; PUMP_VFD_READY; INTERNAL:VFD002:R2 | INTERNAL; PUMP_RUNNING; INTERNAL:VFD002:R3 | INTERNAL; PUMP_FAULT; BOTTLE_INFEED; BOTTLE_NEST_1; BOTTLE_NEST_2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

E-10 PLC DIGITAL INPUTS - MODULE DI001

FICTIONAL CONCEPT DESIGN - NOT FOR CONSTRUCTION

PLC digital inputs - module DI001

A

B

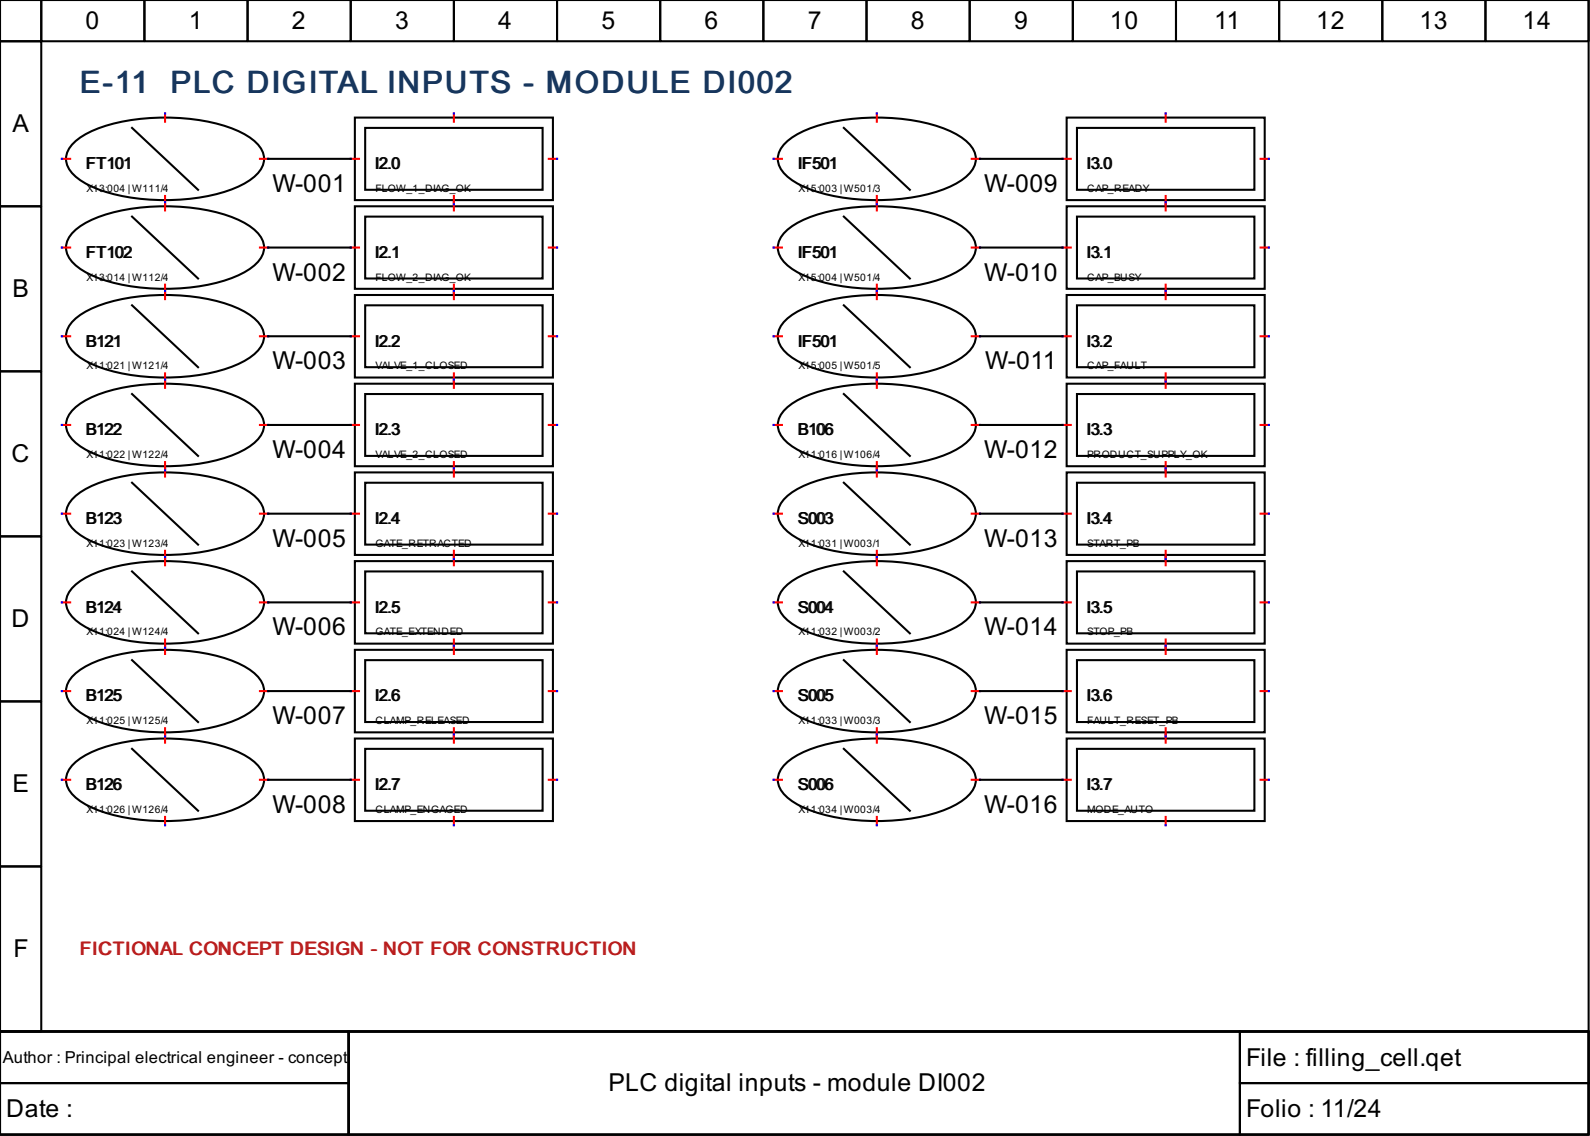
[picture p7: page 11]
FLOW_1_DIAG_OK; FLOW_2_DIAG_OK; VALVE_1_CLOSED; VALVE_2_CLOSED; GATE_RETRACTED; GATE_EXTENDED; CLAMP_RELEASED; CLAMP_ENGAGED; CAP_READY; CAP_BUSY; CAP_FAULT; PRODUCT_SUPPLY_OK; START_PB; STOP_PB; FAULT_RESET_PB; MODE_AUTO

E-11 PLC DIGITAL INPUTS - MODULE DI002

FICTIONAL CONCEPT DESIGN - NOT FOR CONSTRUCTION

PLC digital inputs - module DI002

A

B

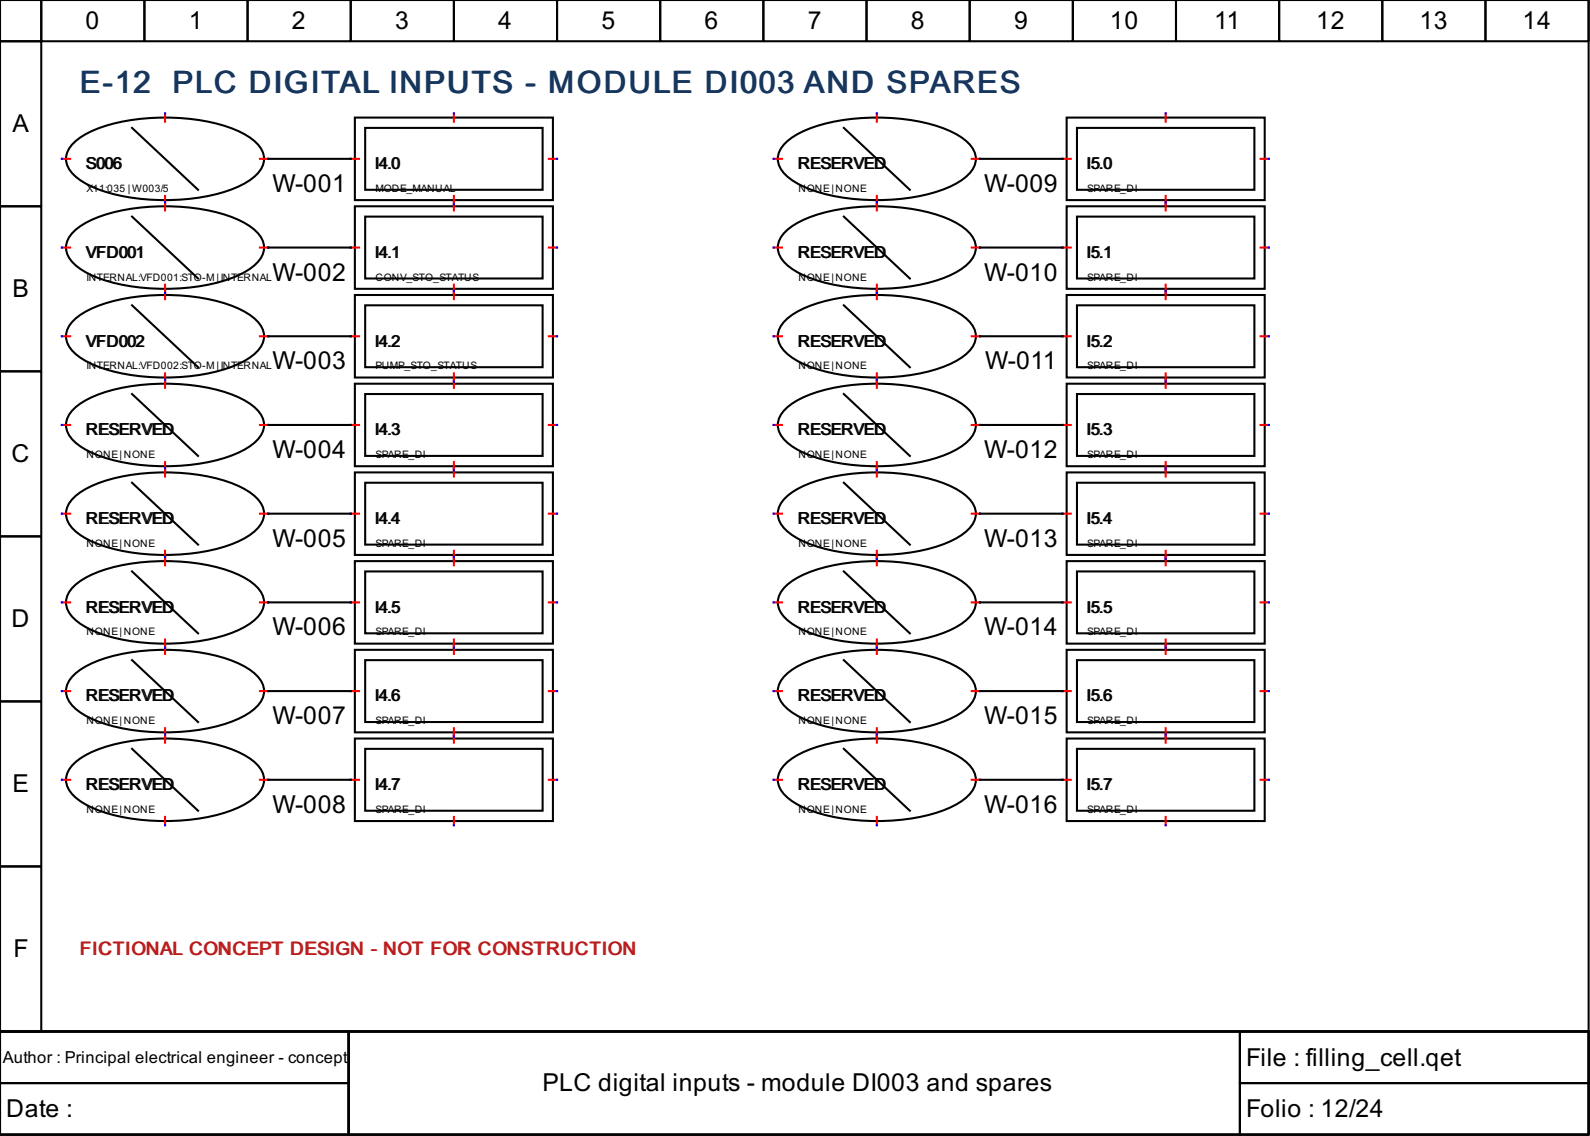
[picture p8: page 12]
MODE_MANUAL; VFD001; CONV_STO_STATUS; VFD002; PUMP_STO_STATUS; RESERVED; NONE|NONE; SPARE_DI

E-12 PLC DIGITAL INPUTS - MODULE DI003 AND SPARES

INTERNAL:VFD001:STO-M | INTERNAL

INTERNAL:VFD002:STO-M | INTERNAL

FICTIONAL CONCEPT DESIGN - NOT FOR CONSTRUCTION

PLC digital inputs - module DI003 and spares

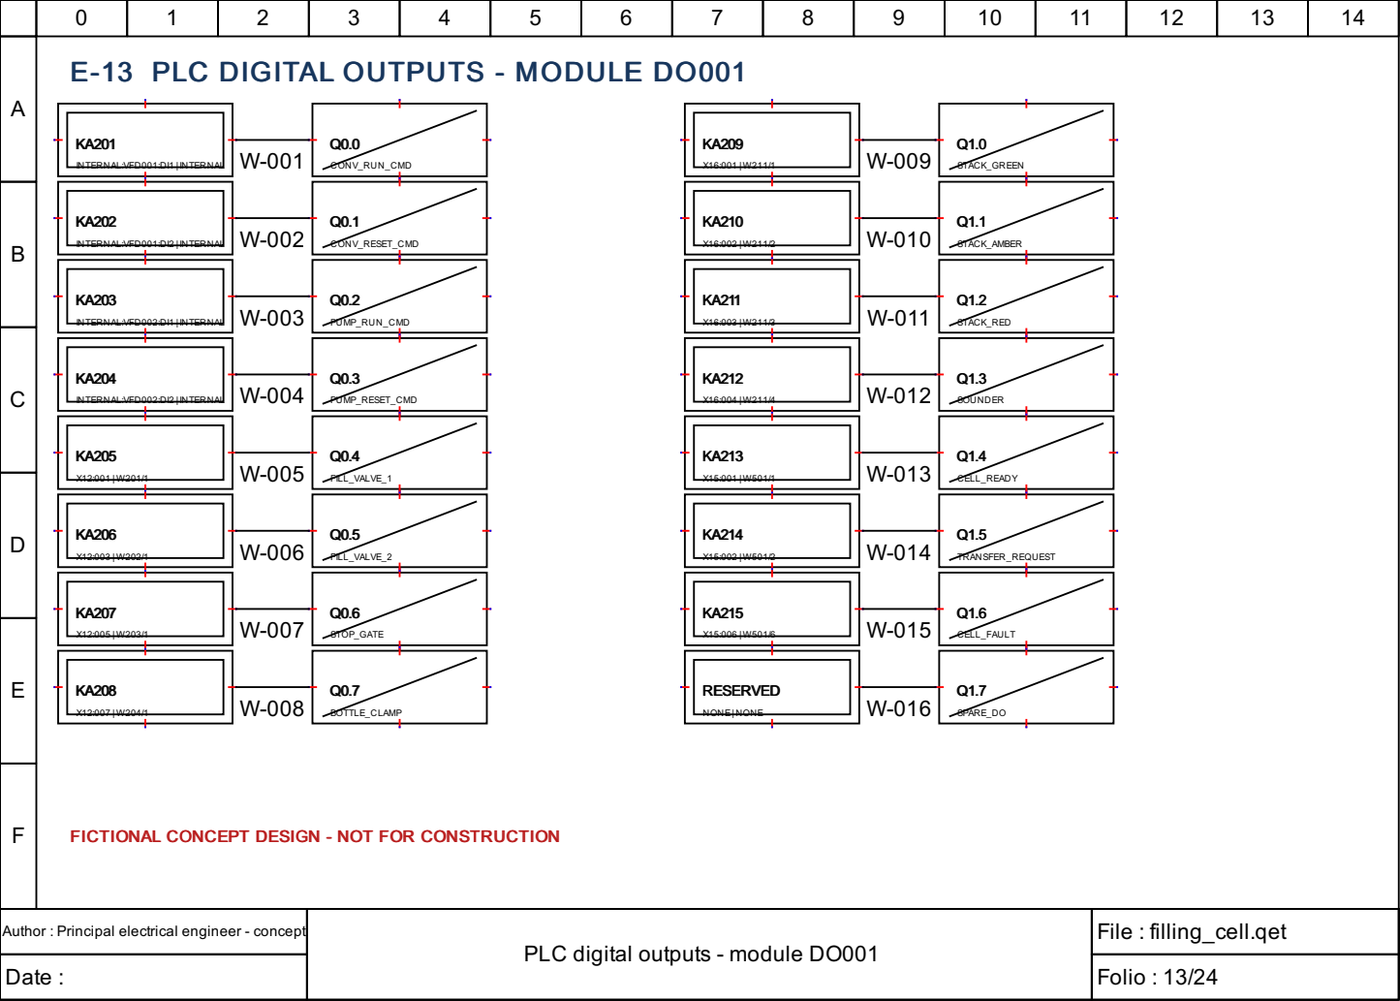
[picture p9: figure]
PLC digital outputs - module DO001; E-13 PLC DIGITAL OUTPUTS - MODULE DO001; INTERNAL:VFD001:DI1 | INTERNAL; CONV_RUN_CMD; INTERNAL:VFD001:DI2 | INTERNAL; CONV_RESET_CMD; INTERNAL:VFD002:DI1 | INTERNAL; PUMP_RUN_CMD; INTERNAL:VFD002:DI2 | INTERNAL; PUMP_RESET_CMD; FILL_VALVE_1; FILL_VALVE_2; STOP_GATE; BOTTLE_CLAMP; STACK_GREEN; STACK_AMBER; STACK_RED; SOUNDER; CELL_READY; TRANSFER_REQUEST; CELL_FAULT; RESERVED; NONE|NONE; SPARE_DO

# FICTIONAL CONCEPT DESIGN - NOT FOR CONSTRUCTION

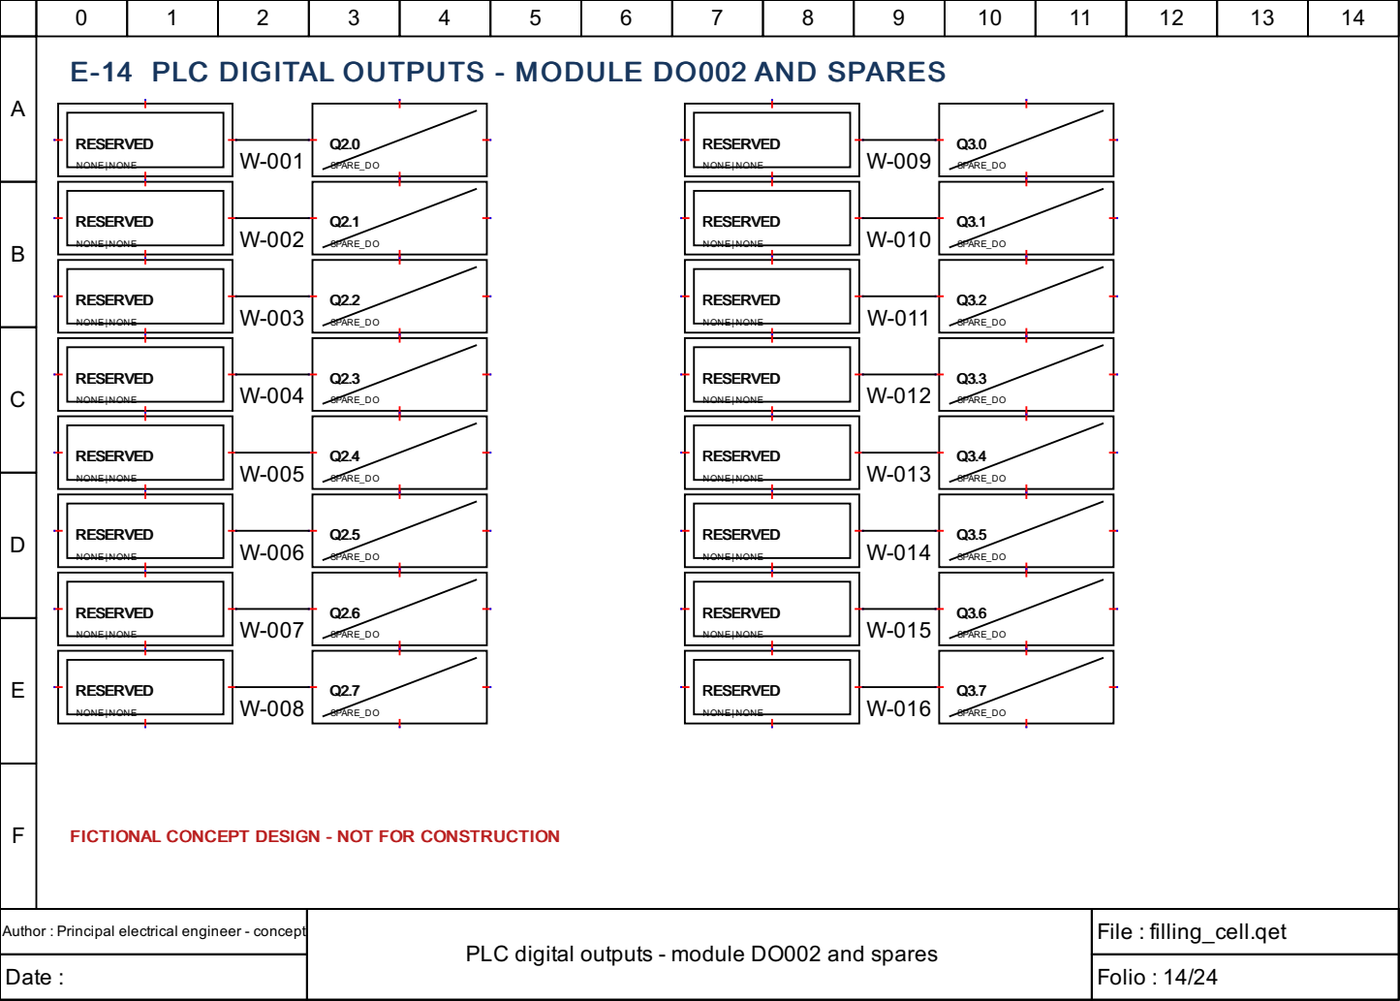
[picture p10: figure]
RESERVED; NONE|NONE; SPARE_DO

# PLC digital outputs - module DO002 and spares

# E-14 PLC DIGITAL OUTPUTS - MODULE DO002 AND SPARES

# FICTIONAL CONCEPT DESIGN - NOT FOR CONSTRUCTION

A

B

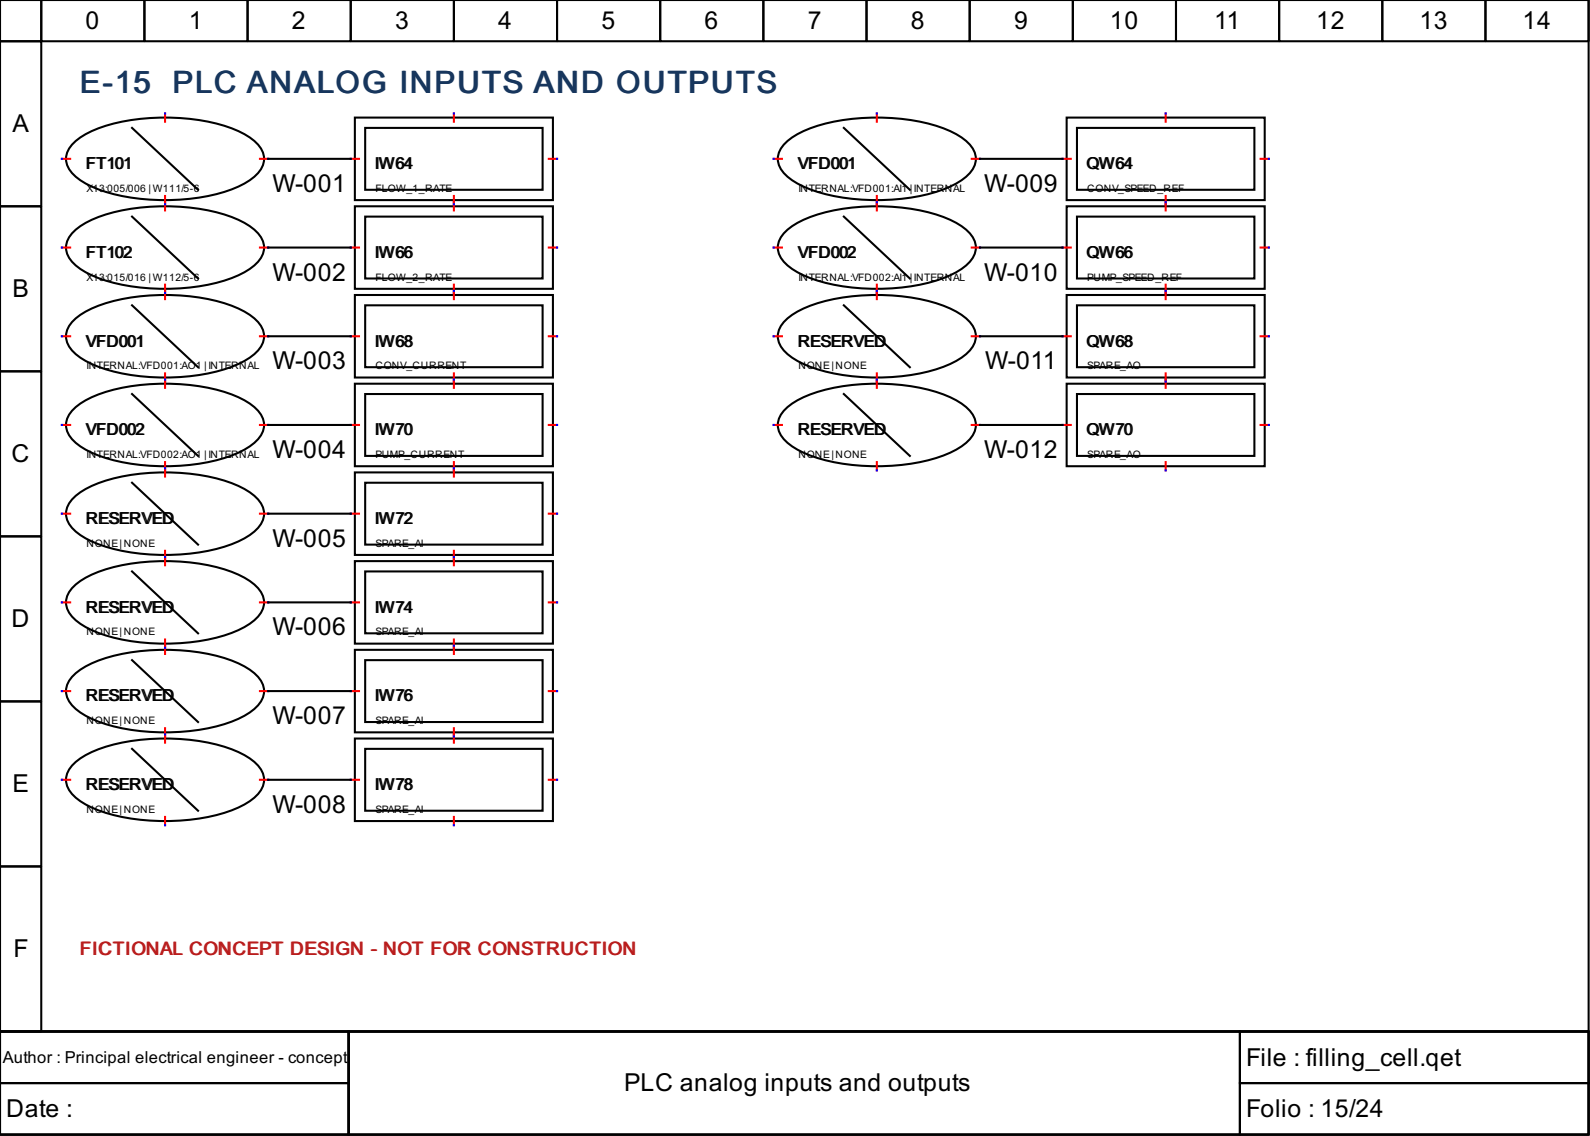
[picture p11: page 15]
FLOW_1_RATE; FLOW_2_RATE; VFD001; INTERNAL:VFD001:AO1 | INTERNAL; CONV_CURRENT; VFD002; INTERNAL:VFD002:AO1 | INTERNAL; PUMP_CURRENT; RESERVED; NONE|NONE; SPARE_AI; INTERNAL:VFD001:AI1 | INTERNAL; CONV_SPEED_REF; INTERNAL:VFD002:AI1 | INTERNAL; PUMP_SPEED_REF; SPARE_AO

E-15 PLC ANALOG INPUTS AND OUTPUTS

FICTIONAL CONCEPT DESIGN - NOT FOR CONSTRUCTION

PLC analog inputs and outputs

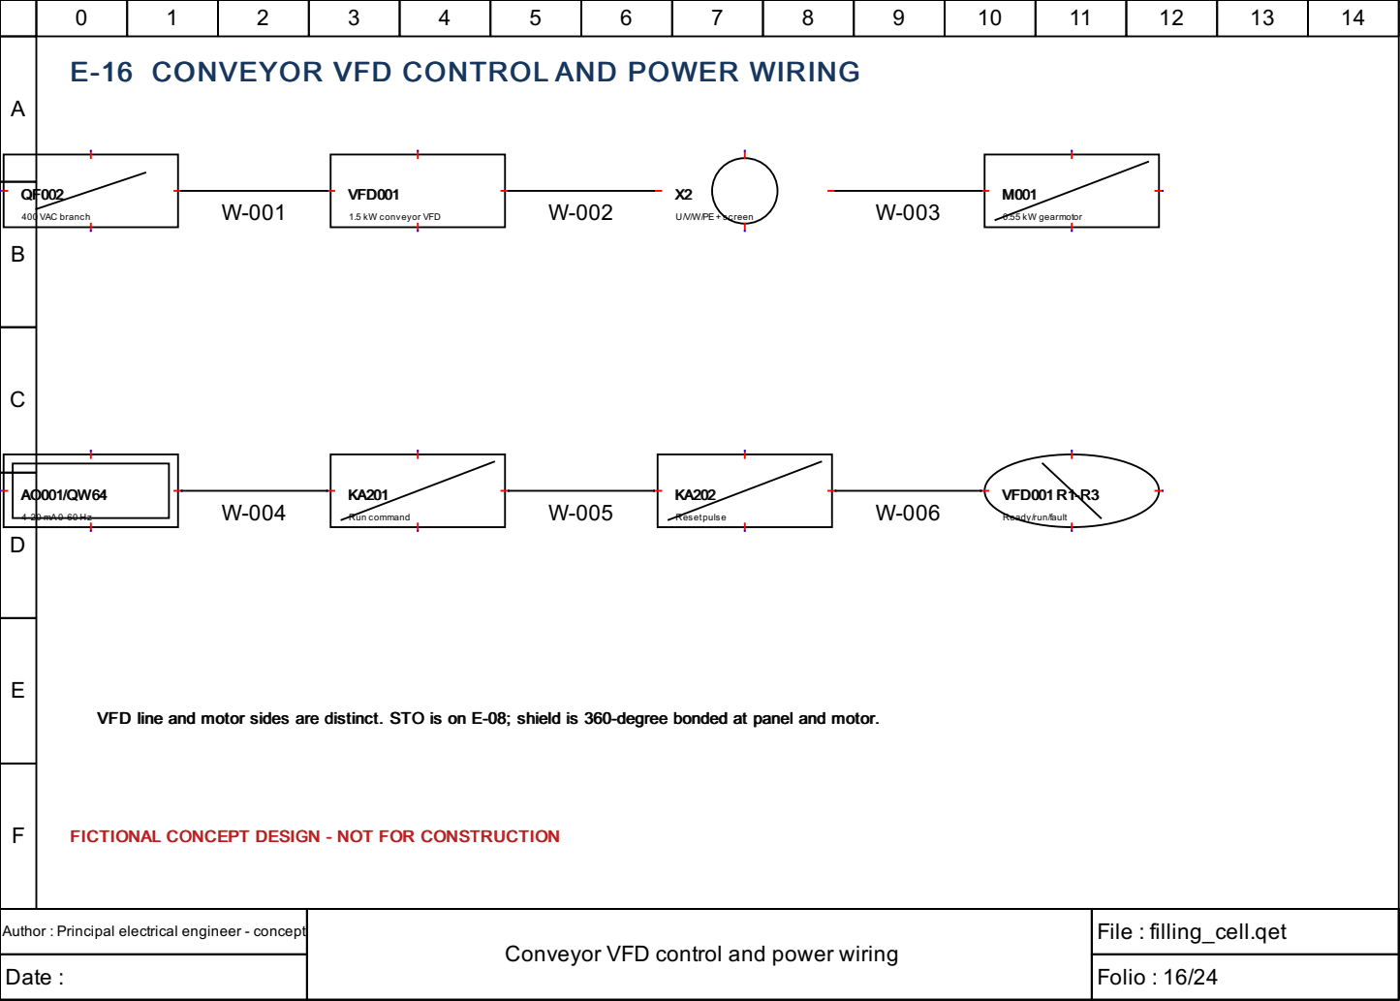
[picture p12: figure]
Conveyor VFD control and power wiring; 400 VAC branch; VFD001; 1.5 kW conveyor VFD; U/V/W/PE+ screen; 0.55 kW gearmotor; Run command; Resetpulse; VFD001 R1-R3; Ready/run/fault

# E-16 CONVEYOR VFD CONTROL AND POWER WIRING

# FICTIONAL CONCEPT DESIGN - NOT FOR CONSTRUCTION

VFD line and motor sides are distinct. STO is on E-08; shield is 360-degree bonded at panel and motor.

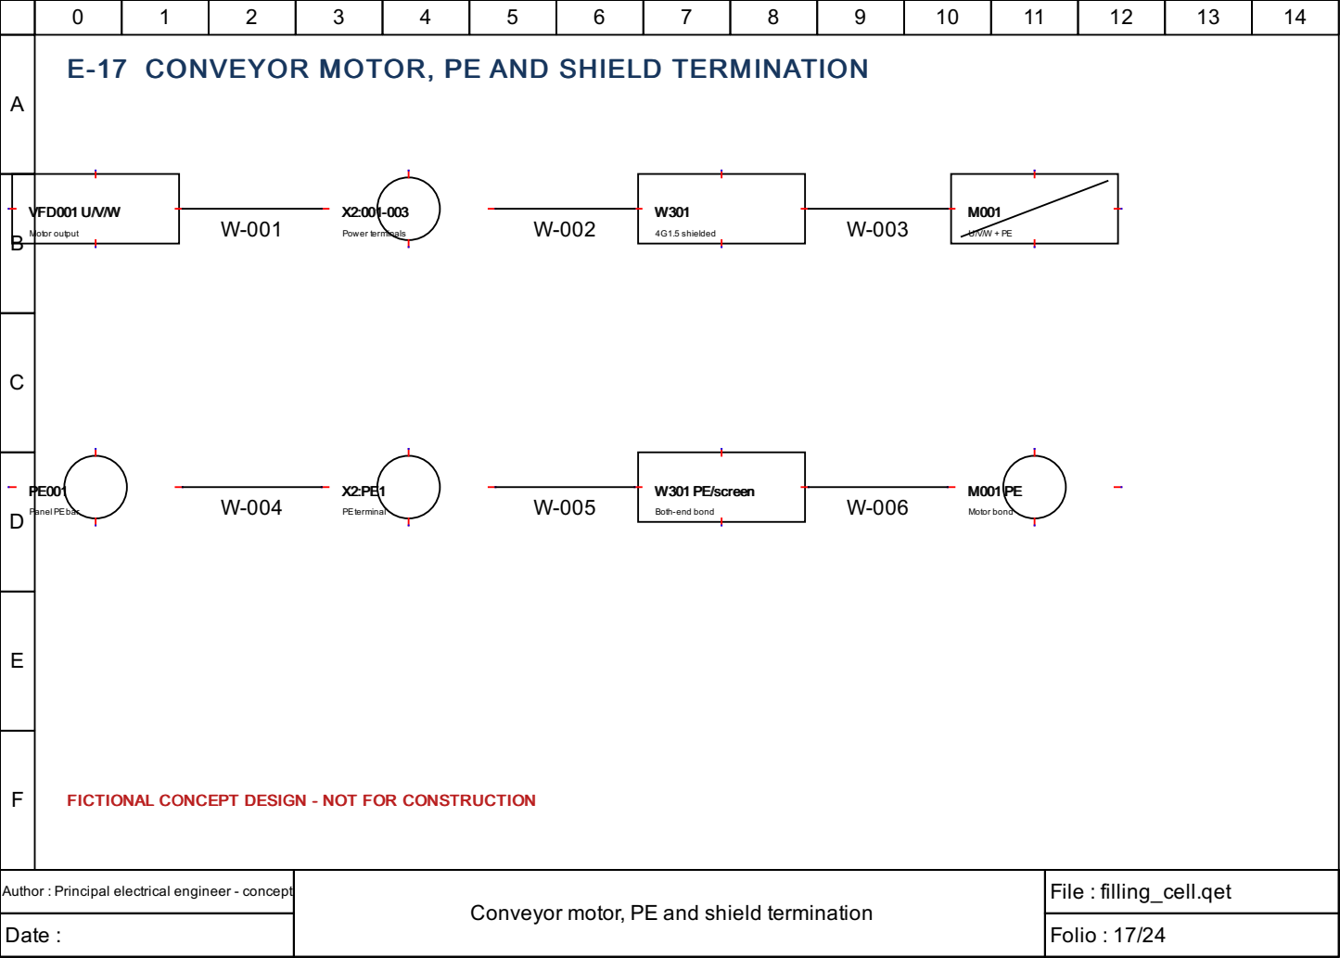
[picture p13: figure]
VFD001 U/V/W; Motor output; Power terminals; 4G1.5 shielded; Panel PEbar; PEterminal; W301 PE/screen; Both-end bond; Motor bond

# Conveyor motor, PE and shield termination

# E-17 CONVEYOR MOTOR, PE AND SHIELD TERMINATION

# FICTIONAL CONCEPT DESIGN - NOT FOR CONSTRUCTION

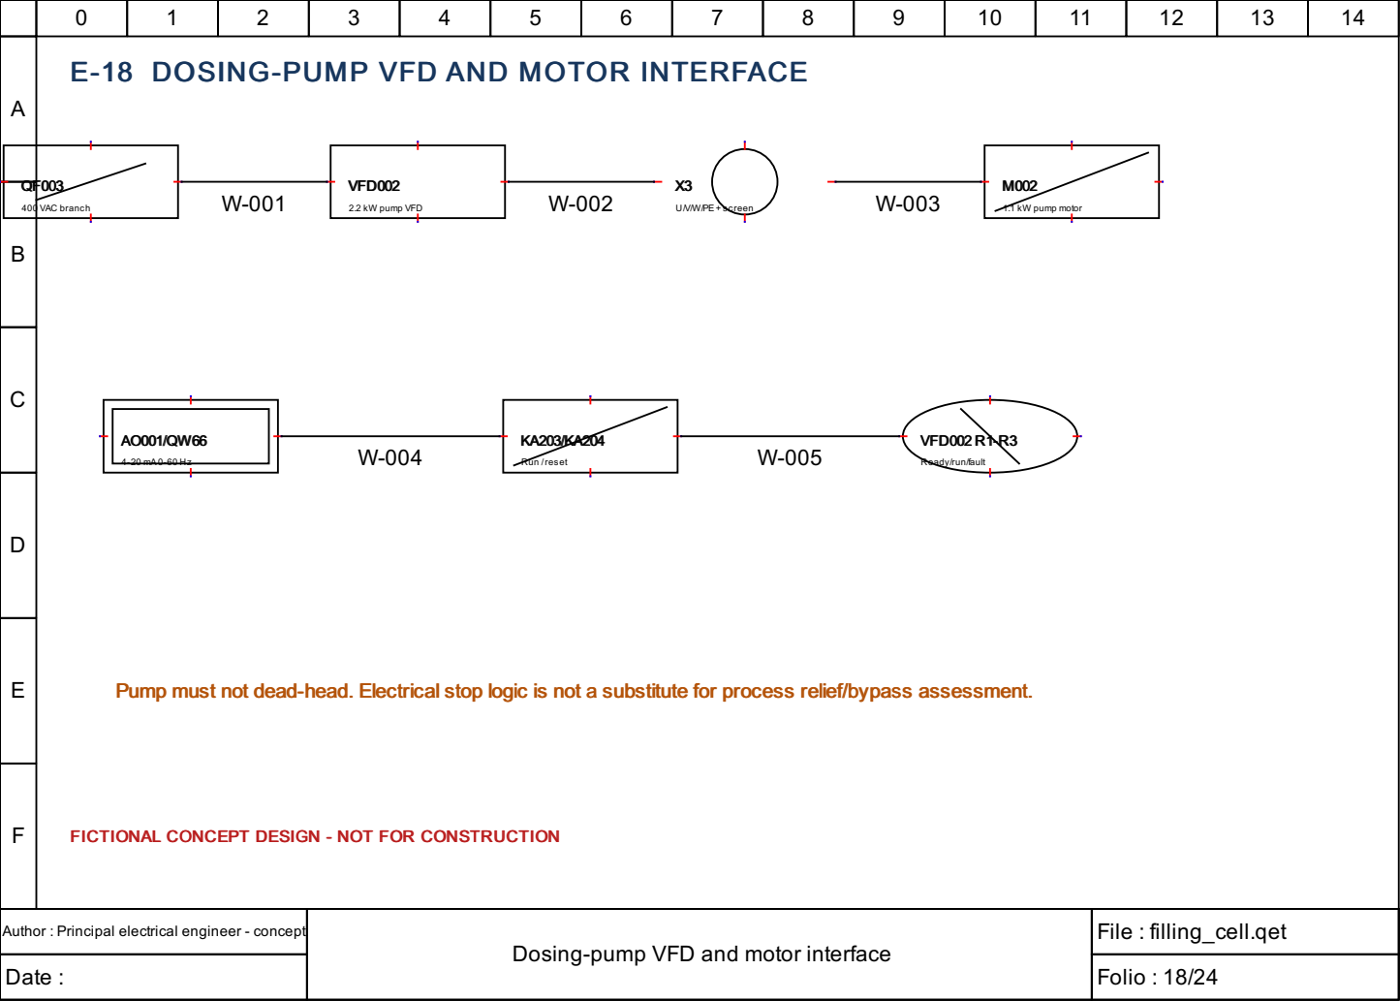
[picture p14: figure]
Dosing-pump VFD and motor interface; 400 VAC branch; VFD002; 2.2 kW pump VFD; U/V/W/PE+ screen; 1.1 kW pump motor; Run /reset; VFD002 R1-R3; Ready/run/fault

# E-18 DOSING-PUMP VFD AND MOTOR INTERFACE

# FICTIONAL CONCEPT DESIGN - NOT FOR CONSTRUCTION

Pump must not dead-head. Electrical stop logic is not a substitute for process relief/bypass assessment.

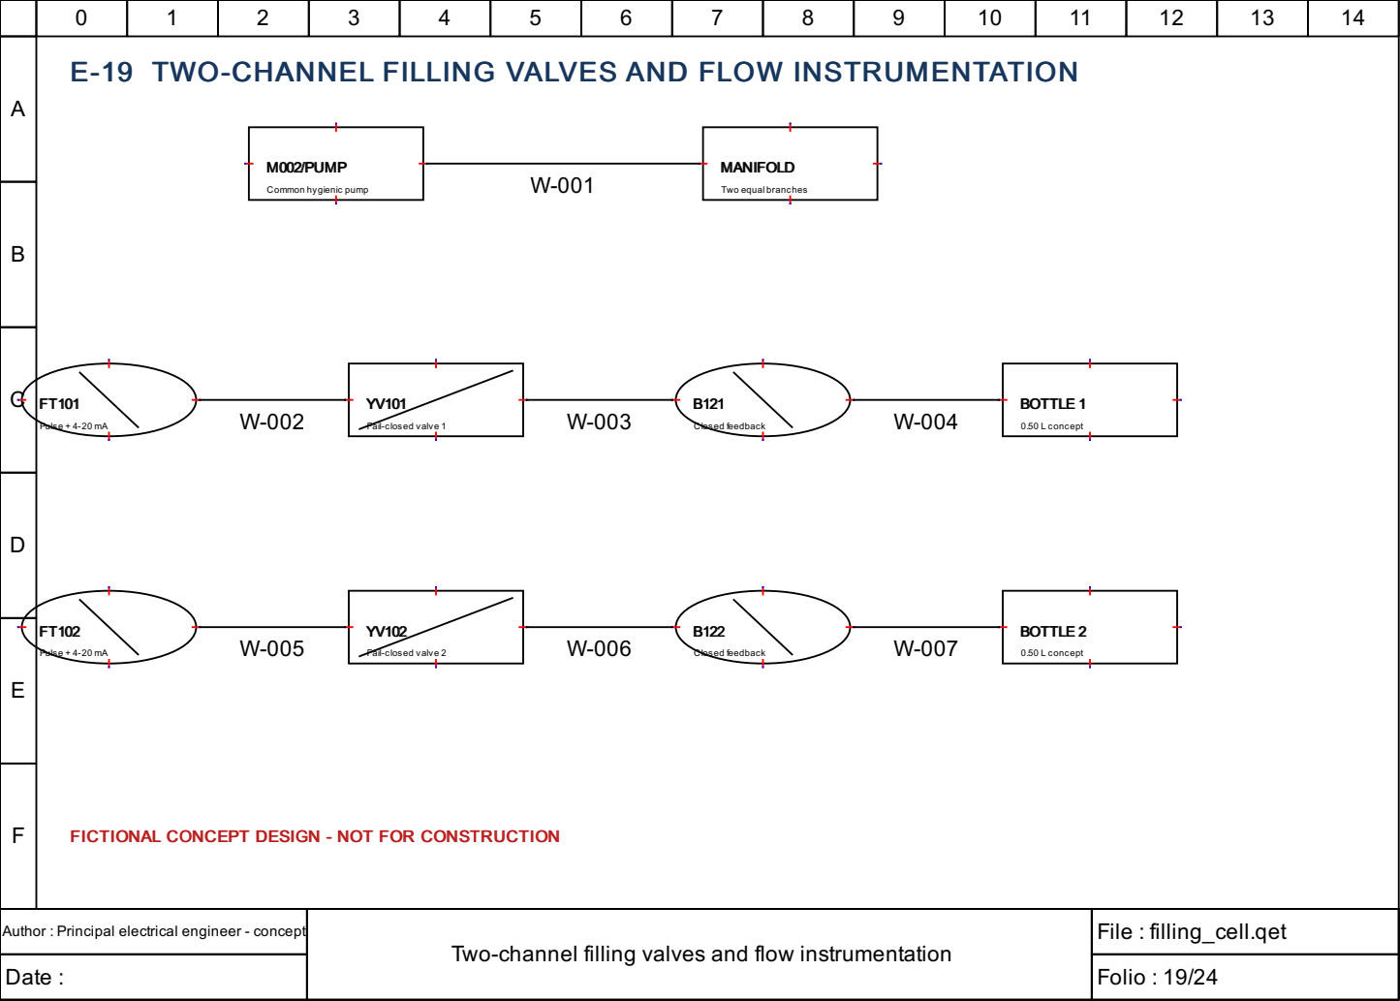
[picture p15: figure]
M002/PUMP; Common hygienic pump; MANIFOLD; Two equal branches; Pulse + 4-20 mA; Fail-closed valve 1; Closed feedback; BOTTLE 1; 0.50 L concept; Fail-closed valve 2; BOTTLE 2

# Two-channel filling valves and flow instrumentation

# E-19 TWO-CHANNEL FILLING VALVES AND FLOW INSTRUMENTATION

# FICTIONAL CONCEPT DESIGN - NOT FOR CONSTRUCTION

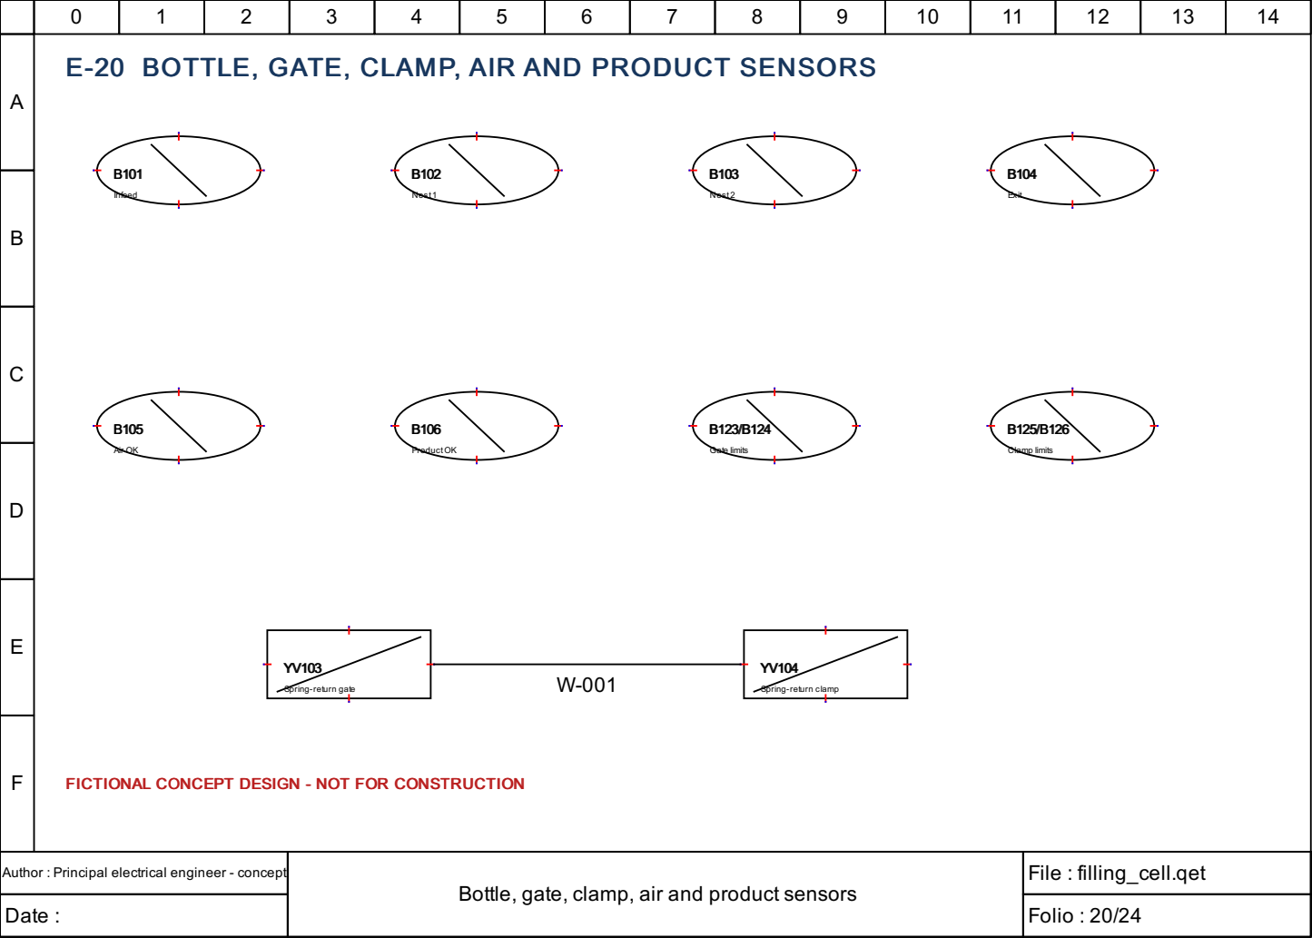
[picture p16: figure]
Infeed; Nest1; Nest2; Exit; Air OK; ProductOK; Gate limits; Clamp limits; Spring-return gate; Spring-return clamp

# Bottle, gate, clamp, air and product sensors

# E-20 BOTTLE, GATE, CLAMP, AIR AND PRODUCT SENSORS

# FICTIONAL CONCEPT DESIGN - NOT FOR CONSTRUCTION

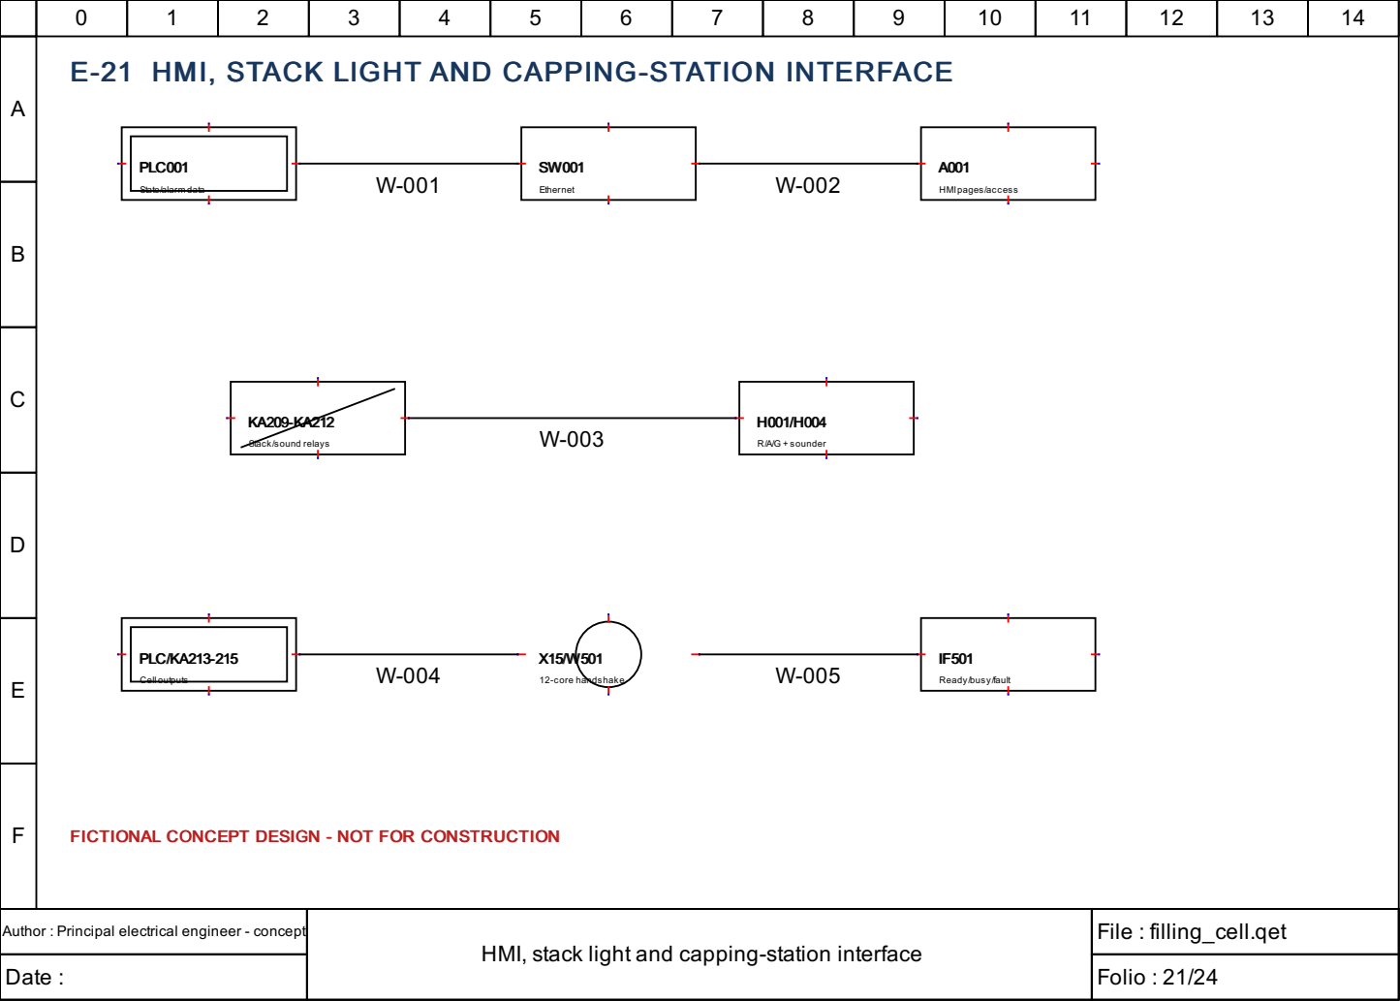
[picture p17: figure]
PLC001; State/alarm data; Ethernet; HMIpages/access; Stack/sound relays; R/A/G + sounder; PLC/KA213-215; Cell outputs; 12-core handshake; Ready/busy/fault

# HMI, stack light and capping-station interface

# E-21 HMI, STACK LIGHT AND CAPPING-STATION INTERFACE

# FICTIONAL CONCEPT DESIGN - NOT FOR CONSTRUCTION

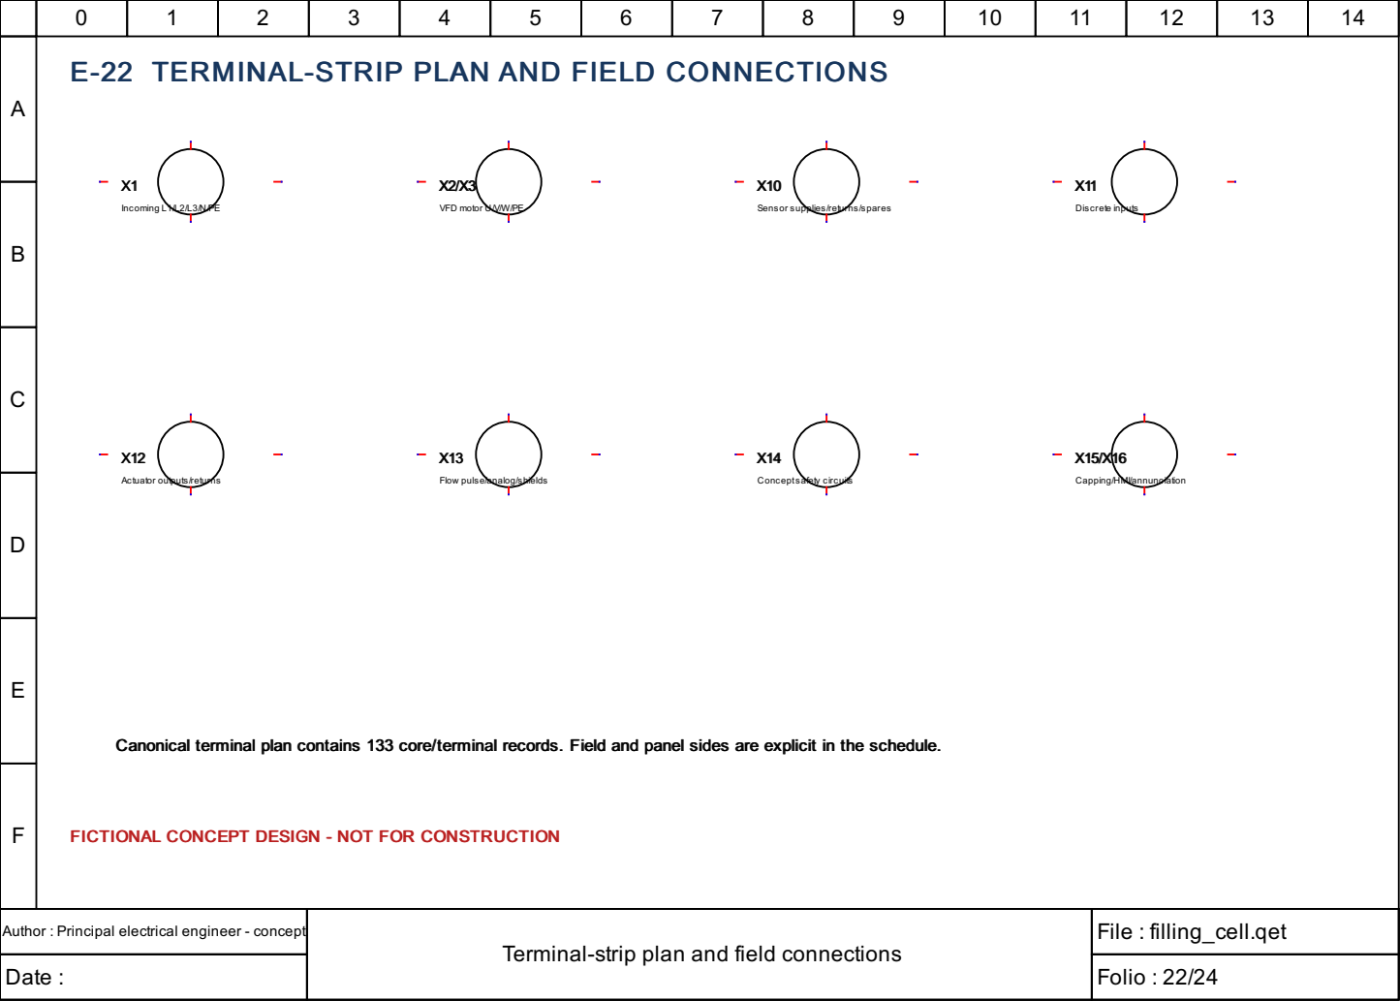
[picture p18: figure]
Incoming L1/L2/L3/N/PE; VFD motor U/V/W/PE; Sensor supplies/returns/spares; Discrete inputs; Actuator outputs/returns; Flow pulse/analog/shields; Conceptsafety circuits; Capping/HMI/annunciation

# Terminal-strip plan and field connections

# E-22 TERMINAL-STRIP PLAN AND FIELD CONNECTIONS

# FICTIONAL CONCEPT DESIGN - NOT FOR CONSTRUCTION

Canonical terminal plan contains 133 core/terminal records. Field and panel sides are explicit in the schedule.

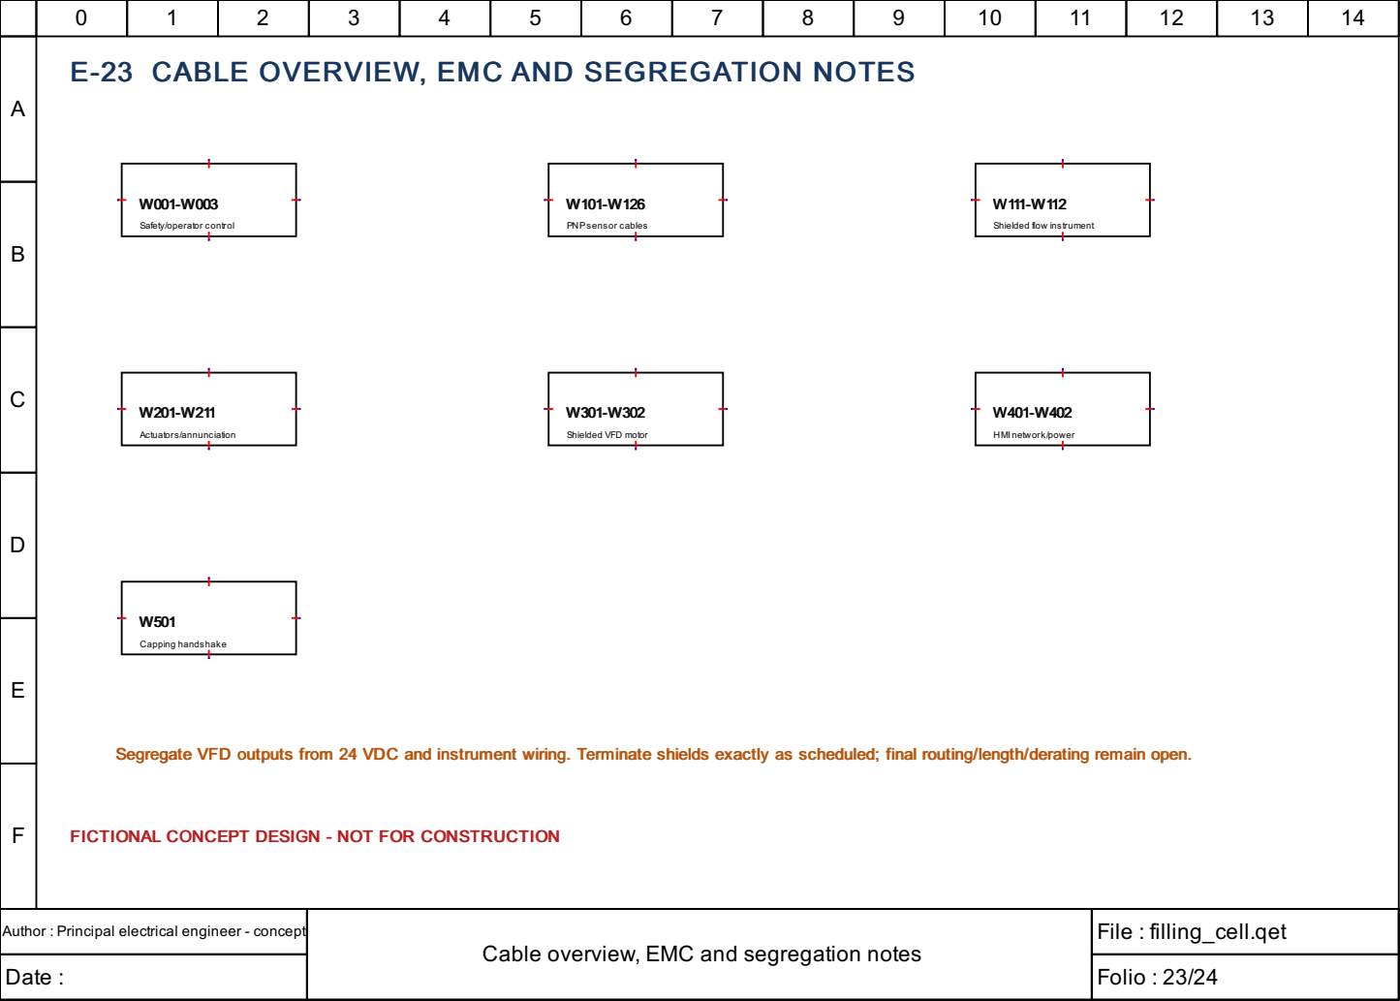
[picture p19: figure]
Safety/operator control; PNPsensor cables; Shielded flow instrument; Actuators/annunciation; Shielded VFD motor; HMInetwork/power; Capping handshake

# Cable overview, EMC and segregation notes

# E-23 CABLE OVERVIEW, EMC AND SEGREGATION NOTES

# FICTIONAL CONCEPT DESIGN - NOT FOR CONSTRUCTION

Segregate VFD outputs from 24 VDC and instrument wiring. Terminate shields exactly as scheduled; final routing/length/derating remain open.

A

B

C

D

E

F

# Spare capacity, general notes and commissioning prerequisites

# E-24 SPARE CAPACITY, GENERAL NOTES AND COMMISSIONING PREREQUISITES

# FICTIONAL CONCEPT DESIGN - NOT FOR CONSTRUCTION

CONCEPTUALSAFETYARCHITECTURE- REQUIRESREVIEW,RISKASSESSMENT,
VERIFICATION AND VALIDATION BYAQUALIFIED MACHINERY-SAFETYENGINEER. NOPERFORMANCELEVEL,SIL,CATEGORYOR REGULATORYCOMPLIANCEISCLAIMED.

DI

35/48 used | 13 spare

DO

15/32 used | 17 spare

AI

4/8 used | 4 spare

AO

2/4 used | 2 spare

GENERAL: final device selections, fault-current/coordination, conductor sizes, voltage drop, EMC and thermal analysis require project data.

NETWORK: Ethernet loss does not substitute for hardwired stop; PLC controls drives through hardwired commands and analog references.

COMMISSIONING: test every I/O point, scaling, sensor, valve, drive, handshake, restart and fault response before process use.

SAFETY: this drawing only describes a conceptual boundary. Qualified risk assessment, verification and validation remain mandatory.

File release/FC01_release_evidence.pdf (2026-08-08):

FC01 | Revision G | 2026-08-08 | Evidence summary - not a native acceptance certificate | Page 1

# FC01 compact two-nozzle filling cell

# Siemens-authoritative controls and bounded NVIDIA quality architecture

FICTIONAL ENGINEERING PROJECT - NOT FOR CONSTRUCTION

CONCEPTUAL SAFETY ARCHITECTURE - REQUIRES PROJECT-SPECIFIC RISK ASSESSMENT, DESIGN, VERIFICATION AND VALIDATION BY A QUALIFIED MACHINERY-SAFETY ENGINEER. NO PERFORMANCE LEVEL, SIL, CATEGORY, CE/UKCA CONFORMITY OR REGULATORY COMPLIANCE IS CLAIMED.

Release status | What is implemented | What remains blocked
CLOUD-READY / NATIVE-EXECUTION-READY CANDIDATE | Revision-G Git-object authority; disabled-by-default secure cloud IaC; exact native-tool inventories; 47-node immutable PLC/AI contract; production-shaped edge/data pipeline; commissioning blank records; re-executed native FreeCAD evidence. | Terraform provider plan/apply; TIA/WinCC compile/archive; Startdrive; PLCSIM; site electrical inputs; real dataset/model/target runtime; physical FAT/SAT and qualified review.

This report is an evidence index. It is not proof of construction readiness, functional safety, native compile, FAT, SAT, electrical test, physical commissioning or AI performance.

FC01 | Revision G | 2026-08-08 | Evidence summary - not a native acceptance certificate | Page 2

# Integrated architecture and deterministic ownership

The PLC owns all machine sequence, interlocks, timeouts, product disposition and transfer permission. THE NVIDIA VISION SUBSYSTEM IS NON-SAFETY-RELATED AND MUST NOT COMMAND HAZARDOUS MOTION, BYPASS PLC INTERLOCKS OR BE USED AS THE SOLE MEANS OF PERSONNEL PROTECTION.

Layer | Owner | Deterministic responsibility | Failure behavior
Field / power | Electrical | Identified device, cable/core, terminal and I/O channel | Fail-closed valves; external safety removes hazardous energy
Equipment control | S7-1500 FB instances | Gate, clamp, two fill channels, conveyor/pump VFD, capper | Module timeout/contradiction fault; outputs safe
Machine coordinator | S7-1500 | Legal states, accepted command edges, no automatic restart | HOLDING, CONTROLLED_STOPPING or FAULTED
Operator interface | MTP700 Unified | Role-checked handshake; feedback and disabled reason | No direct physical-output writes
Quality vision | NVIDIA edge service | Securely acquire request and publish one correlated immutable result | Malformed/stale/low-confidence/fault -> quality hold
Regression | Python + asyncua | Sequence fault injection and encrypted real server/client transport | Design evidence only; never PLCSIM or production-endpoint proof

Machine states: UNINITIALIZED, INITIALIZING, STOPPED, READY, AUTOMATIC, MANUAL_SETUP, HOLDING, CONTROLLED_STOPPING, FAULTED and RECOVERY_RESET. Reset returns to STOPPED and never initiates motion.

FC01 | Revision G | 2026-08-08 | Evidence summary - not a native acceptance certificate | Page 3

# Selected Siemens and edge hardware baseline

Function | Selected item | Order number / status | Verification boundary
PLC | SIMATIC S7-1500 CPU 1511-1 PN | 6ES7511-1AL03-0AB0 | Current official lifecycle checked; V20 device catalog/compile open
Pulse counting | TM Count 2x24V | 6ES7550-1AA01-0AB0 | Two independent 24 V pulse channels; TIA configuration open
DI / DO / AI | DI 32 HF; DQ 32 HF; AI 8xU/I HF | 6ES7521-1BL00-0AB0; 6ES7522-1BL01-0AB0; 6ES7531-7NF00-0AB0 | Front connectors, wiring and catalog compatibility open
HMI | MTP700 Unified Comfort | 6AV2128-3GB06-0AX1 | WinCC V20 compile/licence open
Drives | Two SINAMICS G120C PN 0.75 kW | 6SL3210-1KE12-3UF2 | Ratings provisional; Startdrive absent
Network | SCALANCE XC208 managed plus S615 firewall | 6GK5208-0BA00-2AC2; 6GK5615-0AA01-2AA2 | VLAN/firewall architecture selected; native policy and site approval open
Vision | Jetson Orin NX 16GB on industrial carrier | Carrier/integration SKU TBD | Carrier, thermals, EMC, camera and real dataset open

Authoritative engineering target: TIA Portal V20, executable/product version 2000.0.9501.1. Installed STEP 7 and WinCC V20 components do not prove usable licence entitlement. Current identity is not authorized for TIA Openness. Startdrive and PLCSIM are absent.

FC01 | Revision G | 2026-08-08 | Evidence summary - not a native acceptance certificate | Page 4

# PLC-AI v3 acceptance contract

Transport selection: encrypted OPC UA across a routed quality zone. The PLC publishes one immutable request and holds its request until coherent capture acknowledgement or a terminal result. Results are accepted only for the current session/ID with fresh heartbeat, healthy service/camera/model, approved model/dataset/calibration identities, allowed disposition and reasons, sufficient confidence, valid timing and a non-contradictory payload.

PLC-owned nodes (13) | NVIDIA-owned nodes (34) | Acceptance rule
Enable, trigger, inspection/session identity, recipe/count/fill target, PLC heartbeat, exact result ACK, maintenance mode and expected dataset/calibration IDs | Ready/busy/capture/state/health; immutable quality payload; disposition/reasons/confidence; model/dataset/calibration identities; diagnostic timestamps/timing; edge heartbeat/diagnostics/queue | Payload publishes before RESULT_VALID and remains immutable until exact ACK. PLC-derived monotonic result age is authoritative; edge UTC is diagnostic. Any stale, malformed, unhealthy, uncertain or contradictory condition enters HOLD/FAULT.

The adapter requires Basic256Sha256 SignAndEncrypt, X.509 application/user identity, controlled trust/CRL stores and an exact 47-node typed map. Local certificate-backed asyncua tests use a synthetic endpoint. No model is delivered. No training, ONNX export, TensorRT engine, DeepStream execution, accuracy, confusion matrix, false-accept/reject analysis or production latency is claimed. The RTX 5060 Laptop GPU does not substitute for the absent CUDA/TAO/DeepStream target stack or representative dataset.

FC01 | Revision G | 2026-08-08 | Evidence summary - not a native acceptance certificate | Page 5

# Revision-G cloud and NVIDIA execution readiness

Work package | Revision-G controlled result | Open acceptance boundary
Secure cloud foundation | Separate private Windows and Linux GPU environments, IAP-only administration, separate keyless service accounts, budget/schedule/storage controls and disabled VM creation flags | Terraform/OpenTofu native validate/plan, project IAM/cost approval and any provisioning
Acquisition/runtime | Exactly-once recorded-image source, bounded preprocessing, production-prohibited mock backend and hash-gated ONNX adapter boundary | Physical camera/lens/light, actual tensor contract and target runtime
Dataset/evaluation | Versioned annotation/manifest schemas, file hashes, lot/session split controls, duplicate/leakage checks and FAR/FRR evaluation math | Representative independently labeled multi-lot data, approved thresholds and model-change approval
Platform policy | DeepStream 9.1 and TAO 7.0.1 tracked; generic TensorRT 11.1 is not treated as a Jetson compatibility lock | Selected JetPack/carrier image, CUDA/TensorRT/DeepStream/TAO execution and deployment validation
Electrical delta | Separate provisional 24 V branches: 60 W edge, 12 W camera, 20 W lighting and 8 W service/network; X200 and switch-port reservations | Selected devices, inrush, protection, cable, voltage-drop, thermal, EMC and native schematic/CAD incorporation
Service lifecycle | Schema-controlled configuration, structured diagnostics, durable event-store boundary, health/metrics, rollback and troubleshooting procedures | Site PKI/time/retention/privacy policy, production endpoint and operational acceptance
Qualified-review preparation | Conceptual hazard/input, safety-function, standards-applicability and open-decision registers plus blank signature block | Named qualified electrical and machinery-safety reviewers, project inputs, validated design and signed evidence

Synthetic fixtures and local timing harnesses prove software plumbing only. They cannot authorize production READY, establish optical feasibility, or support any accuracy, false-accept, false-reject, throughput or latency claim.

FC01 | Revision G | 2026-08-08 | Evidence summary - not a native acceptance certificate | Page 6

# Validation evidence and release blockers

Gate | Evidence | Status
Canonical consistency | 551 inherited engineering-validator checks plus the dedicated Revision-G verifier cover generator parity, cloud security, evidence boundaries, commissioning blanks and prohibited artifacts. The standalone electrical delta is not incorporated into every authority. | PARTIAL
Deterministic regression | 99 Siemens/simulator/source/native-contract + 86 edge-service + 17 interface-harness tests; 32 process and 28 structured behavioral fault-injection cases | SOURCE/LOCAL PASS - not PLCSIM/HIL
Workbook | 27 summary/schedule sheets; deterministic normalized build, formula-error scan and all-sheet rendered review | PASS after final freeze
QElectroTech | Corrected 26-folio QET BCA022BE0B9F... reopened at the exact hash and exported natively to 26 pages. All pages reviewed; folio 25 has one clipped in-body safety sentence and automatic cross-reference resolution is unsupported | NATIVE REOPEN/EXPORT PASS; OVERALL PARTIAL
Panel CAD | FreeCADCmd reopened 165 objects / 148 controlled solids; STEP solid, IGES bounded-face and DXF/hole reimports verified | PASS
TIA / WinCC / drives | V20 installed; no native project, compile, cross-reference, archive restore or Startdrive evidence | BLOCKED
PLCSIM | Not installed | BLOCKED
NVIDIA software | 86/86 edge tests including certificate-backed local asyncua cases; 47-node map, synthetic-backend READY refusal, durable-audit interlock and 28-case behavioral injection pass | PARTIAL - production endpoint/native binding open
NVIDIA model/runtime | Production PLC/PKI, representative dataset, trained model and CUDA/TensorRT/DeepStream target stack absent | MODEL/RUNTIME BLOCKED

Gate totals: 3 PASS, 7 PARTIAL, 11 BLOCKED, 1 OPEN. Release use: controlled design review and continuation in qualified native tools only. Read the manifest, acceptance-gate report and open-input register before work.

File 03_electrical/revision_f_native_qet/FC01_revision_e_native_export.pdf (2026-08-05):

| 0 | 1 | 2 | 3 | 4 | 5 | 6 | 7 | 8 | 9 | 10 | 11 | 12 | 13 | 14

A

B

C

D

E

F

Author: FC01 engineering team | Cover and controlled revision status | File: FC01_revision_e.qet
Date: | | Folio: 1/26

# E-01 COVER AND CONTROLLED REVISION STATUS

## RREEVV EE || 11//2266

### FC01 Compact Filling-Cell Electrical Design Package - Revision E

Selected architecture: CPU 1511-1 PN, local S7-1500 I/O, MTP700 Unified, two G120C PN drives and non-safety NVIDIA inspection.

Native source generated from the controlled Revision-D.1 schedules and first validated with QElectroTech 0.100.0.

OPEN: site supply, fault current, motor data, cable routes, ambient, enclosure duty and qualified safety engineering.

FICTIONAL ENGINEERINGPROJECT - NOT FOR CONSTRUCTION

CONCEPTUALSAFETYARCHITECTURE- REQUIRESPROJECT-SPECIFIC RISKASSESSMENT,DESIGN,VERIFICATION AND VALIDATION BYAQUALIFIED MACHINERY-SAFETYENGINEER.NOPERFORMANCELEVEL,SIL,CATEGORY,CECONFORMITYOR REGULATORYCOMPLIANCEISCLAIMED.

A

B

C

D

E

F

# Author: FC01 engineering team Drawing index

# File: FC01_revision_e.qet

# E-02 DRAWING INDEX

## RREEVV EE || 22//2266

E-01 Cover and controlled revision status

E-02 Drawing index

E-03 Design basis, legend and reference designations

E-04 Single-line incoming power distribution

E-05 Main distribution and branch protection

E-06 24 VDC PELV distribution

E-07 S7-1500 rack and module allocation

E-08 PLC digital inputs I0.0-I1.7

E-09 PLC digital inputs I2.0-I3.7 and spares

E-10 PLC digital outputs Q0.0-Q1.7

E-11 PLC digital outputs Q2.0-Q3.7 and spares

E-12 Analog inputs and shield termination

E-13 TM Count high-speed pulse inputs

E-14 Conveyor G120C power and PROFINETcontrol

E-15 Pump G120C power and PROFINETcontrol

E-16 Motor cables, PE and shield termination

E-17 PROFINETand OTnetwork architecture

E-18 HMI and NVIDIA inspection interface

E-19 Solenoid valves and interposing relays

E-20 Field sensors, flow and level instrumentation

E-21 Stack light, local stations and capper interface

E-22 Terminal strips X100 and X101

E-23 Terminal strips X102/X103, power, common and shields

E-24 Cable schedule and external field connections

E-25 Conceptual safety interface and boundaries

E-26 Spare capacity, BOM coverage and open inputs

FICTIONAL ENGINEERINGPROJECT - NOT FOR CONSTRUCTION

CONCEPTUALSAFETYARCHITECTURE- REQUIRESPROJECT-SPECIFIC RISKASSESSMENT,DESIGN,VERIFICATION AND VALIDATION BYAQUALIFIED MACHINERY-SAFETYENGINEER.NOPERFORMANCELEVEL,SIL,CATEGORY,CECONFORMITYOR REGULATORYCOMPLIANCEISCLAIMED.

A

B

C

D

E

F

# Author: FC01 engineering team Design basis, legend and reference designations

# File: FC01_revision_e.qet

PROTECTIVEDEVICE | PLC /MODULE | SENSOR /INSTRUMENT | ACTUATOR /RELAY | TERMINAL /SHIELD

# E-03 DESIGN BASIS, LEGEND AND REFERENCE DESIGNATIONS

## RREEVV EE || 33//2266

## =FC01+CP01-QS100

### Main isolation

## =FC01+CP01-A100

### PLC/controller

## =FC01+FLD-FT100

### Field instrument

## =FC01+FLD-YV100

### Solenoid actuator

## =FC01+CP01-X100..-X199

### Terminal family

Designation form: =FC01+<location>-<tag>; CP01 control panel, FD01 field, OP01 operator and IF01 external capper interface.

Ordinary PNP 24 VDC field sensing; 4-20 mA analog; TM Count pulse channels; PROFINET Standard Telegram 1 for drives.

PROVISIONAL: 400/230 VAC 3P+N+PE 50 Hz TN-S and 24 VDC PELV are design assumptions pending site confirmation.

FICTIONAL ENGINEERINGPROJECT - NOT FOR CONSTRUCTION

CONCEPTUALSAFETYARCHITECTURE- REQUIRESPROJECT-SPECIFIC RISKASSESSMENT,DESIGN,VERIFICATION AND VALIDATION BYAQUALIFIED MACHINERY-SAFETYENGINEER.NOPERFORMANCELEVEL,SIL,CATEGORY,CECONFORMITYOR REGULATORYCOMPLIANCEISCLAIMED.

A

B

C

D

E

F

# Author: FC01 engineering team Single-line incoming power distribution

# File: FC01_revision_e.qet

POWER SUPPLY | PROTECTIVEDEVICE | PROTECTIVEDEVICE | DEVICE | TERMINAL /SHIELD
E-04 SINGLE-LINE INCOMING POWER DISTRIBUTION | RREEVV EE || 44//2266

## =FC01+FLD-GL100

### Site cable entry

3P+N+PEassumption

## =FC01+CP01-QS100

### Door-coupled main isolator

## =FC01+CP01-QF100

### Main protective device

## =FC01+CP01-PE100

### PE bar and enclosure bonding

## =FC01+CP01-X0

### Incoming distribution terminals

Functional single-line path only; conductor sizing and protection ratings remain open and are not construction values.

PE is not switched. Bond enclosure, mounting plate, door and equipment PE to PE100 using verified conductors.

OPEN: supply earthing system, prospective fault current, SCCR, selectivity, voltage drop and installation method.

FICTIONAL ENGINEERINGPROJECT - NOT FOR CONSTRUCTION

CONCEPTUALSAFETYARCHITECTURE- REQUIRESPROJECT-SPECIFIC RISKASSESSMENT,DESIGN,VERIFICATION AND VALIDATION BYAQUALIFIED MACHINERY-SAFETYENGINEER.NOPERFORMANCELEVEL,SIL,CATEGORY,CECONFORMITYOR REGULATORYCOMPLIANCEISCLAIMED.

A

B

C

D

E

F

# Author: FC01 engineering team Main distribution and branch protection

# File: FC01_revision_e.qet

PROTECTIVEDEVICE | VARIABLE-FREQUENCYDRIVE | VARIABLE-FREQUENCYDRIVE | POWER SUPPLY | PROTECTIVEDEVICE
E-05 MAIN DISTRIBUTION AND BRANCH PROTECTION | RREEVV EE || 55//2266

## =FC01+CP01-QF100

### Main protective device

## =FC01+CP01-U100

### Conveyor G120C PN

## =FC01+CP01-U101

### Pump G120C PN

## =FC01+CP01-PS100

### 24 VDC 20 A supply

## =FC01+CP01-QF110

### 24 VDC branch protection

Separate mains/drive routes from 24 VDC control, instrumentation and Ethernet wiring.

Drive input protection, EMC accessories, braking duty and motor cable selections are provisional pending nameplates and vendor coordination.

FICTIONAL ENGINEERINGPROJECT - NOT FOR CONSTRUCTION

CONCEPTUALSAFETYARCHITECTURE- REQUIRESPROJECT-SPECIFIC RISKASSESSMENT,DESIGN,VERIFICATION AND VALIDATION BYAQUALIFIED MACHINERY-SAFETYENGINEER.NOPERFORMANCELEVEL,SIL,CATEGORY,CECONFORMITYOR REGULATORYCOMPLIANCEISCLAIMED.

A

B

C

D

E

F

# Author: FC01 engineering team 24 VDC PELV distribution

# File: FC01_revision_e.qet

POWER SUPPLY | PROTECTIVEDEVICE | PLC /MODULE | NETWORKNODE | NETWORKNODE
E-06 24 VDC PELV DISTRIBUTION | RREEVV EE || 66//2266

## =FC01+CP01-PS100

### 24 VDC 20 A supply

## =FC01+CP01-QF110

### Electronic branch protection

## =FC01+CP01-A100

### PLC and local modules

## =FC01+CP01-SW100

### Managed switch

## =FC01+CP01-PC200

### NVIDIA edge compute

Protected branches: PLC/I-O, HMI, relays/solenoids, network/security and vision/lighting; exact channel ratings remain a native design input.

0 V reference and functional-earth/shield paths are controlled separately; do not substitute shield drain for protective earth.

FICTIONAL ENGINEERINGPROJECT - NOT FOR CONSTRUCTION

CONCEPTUALSAFETYARCHITECTURE- REQUIRESPROJECT-SPECIFIC RISKASSESSMENT,DESIGN,VERIFICATION AND VALIDATION BYAQUALIFIED MACHINERY-SAFETYENGINEER.NOPERFORMANCELEVEL,SIL,CATEGORY,CECONFORMITYOR REGULATORYCOMPLIANCEISCLAIMED.

A

B

C

D

E

F

# Author: FC01 engineering team S7-1500 rack and module allocation

# File: FC01_revision_e.qet

PLC /MODULE | PLC /MODULE | PLC /MODULE | PLC /MODULE | PLC /MODULE
E-07 S7-1500 RACK AND MODULE ALLOCATION | RREEVV EE || 77//2266

## =FC01+CP01-A100

### SIMATIC S7-1500 CPU 1511-1 PN

6ES7511-1AL03-0AB0

## =FC01+CP01-A101

### TM Count 2x24V

6ES7550-1AA01-0AB0

## =FC01+CP01-A102

### DI 32x24V DC HF

6ES7521-1BL00-0AB0

## =FC01+CP01-A103

### DQ 32x24V DC/0.5A HF

6ES7522-1BL01-0AB0

## =FC01+CP01-A104

### AI 8xU/I HF

6ES7531-7NF00-0AB0

Rack order: CPU, TM Count, DI, DQ, AI. Memory card, rail, front connectors and load-group wiring require native TIA confirmation.

CPU baseline FS03/FW4.0 is a controlled assumption; delivered hardware state and exact V20 catalog compatibility remain open.

FICTIONAL ENGINEERINGPROJECT - NOT FOR CONSTRUCTION

CONCEPTUALSAFETYARCHITECTURE- REQUIRESPROJECT-SPECIFIC RISKASSESSMENT,DESIGN,VERIFICATION AND VALIDATION BYAQUALIFIED MACHINERY-SAFETYENGINEER.NOPERFORMANCELEVEL,SIL,CATEGORY,CECONFORMITYOR REGULATORYCOMPLIANCEISCLAIMED.

A

B

C

D

E

F

# Author: FC01 engineering team PLC digital inputs I0.0-I1.7

# File: FC01_revision_e.qet

# E-08 PLC DIGITAL INPUTS I0.0-I1.7

## RREEVV EE || 88//2266

I0.0 -A102/CH0 SAFETY_OK-K100 SPARE/NO FIELD TERM -/-

I0.1 -A102/CH1 GUARD_CLOSED_STATUS-S102 X100:1 C001/1

I0.2 -A102/CH2 AIR_PRESSURE_OK-B100 X100:3 C002/1

I0.3 -A102/CH3 PRODUCT_SUPPLY_OK-B101 X100:6 C003/1

I0.4 -A102/CH4 DI_SPARE_DRIVE_REMOVED_01 SPARESPARE/NO FIELD TERM -/-

I0.5 -A102/CH5 DI_SPARE_DRIVE_REMOVED_02 SPARESPARE/NO FIELD TERM -/-

I0.6 -A102/CH6 DI_SPARE_DRIVE_REMOVED_03 SPARESPARE/NO FIELD TERM -/-

I0.7 -A102/CH7 DI_SPARE_DRIVE_REMOVED_04 SPARESPARE/NO FIELD TERM -/-

I1.0 -A102/CH8 DI_SPARE_DRIVE_REMOVED_05 SPARESPARE/NO FIELD TERM -/-

I1.1 -A102/CH9 DI_SPARE_DRIVE_REMOVED_06 SPARESPARE/NO FIELD TERM -/-

I1.2 -A102/CH10 BOTTLE_AT_NEST_1 -B110 X100:9 C004/1

I1.3 -A102/CH11 BOTTLE_AT_NEST_2 -B111 X100:12 C005/1

I1.4 -A102/CH12 GATE_OPEN_FB-B120 X100:15 C006/1

I1.5 -A102/CH13 GATE_CLOSED_FB-B121 X100:18 C007/1

I1.6 -A102/CH14 CLAMP_RELEASED_FB-B122 X100:21 C008/1

I1.7 -A102/CH15 CLAMP_ENGAGED_FB-B123 X100:24 C009/1

FICTIONAL ENGINEERINGPROJECT - NOT FOR CONSTRUCTION

CONCEPTUALSAFETYARCHITECTURE- REQUIRESPROJECT-SPECIFIC RISKASSESSMENT,DESIGN,VERIFICATION AND VALIDATION BYAQUALIFIED MACHINERY-SAFETYENGINEER.NOPERFORMANCELEVEL,SIL,CATEGORY,CECONFORMITYOR REGULATORYCOMPLIANCEISCLAIMED.

A

B

C

D

E

F

# Author: FC01 engineering team PLC digital inputs I2.0-I3.7 and spares

# File: FC01_revision_e.qet

# E-09 PLC DIGITAL INPUTS I2.0-I3.7 AND SPARES

## RREEVV EE || 99//2266

I2.0 -A102/CH16 FILL_VALVE_1_CLOSED_FB-B130 X101:3 C010/1

I2.1 -A102/CH17 FILL_VALVE_2_CLOSED_FB-B131 X101:6 C011/1

I2.2 -A102/CH18 CAPPER_READY-IF140 X101:9 C012/1

I2.3 -A102/CH19 CAPPER_BUSY-IF140 X101:12 C012/4

I2.4 -A102/CH20 CAPPER_COMPLETE-IF140 X101:13 C012/5

I2.5 -A102/CH21 CAPPER_FAULT -IF140 X101:14 C012/6

I2.6 -A102/CH22 LOCAL_RESET_PB-S100 X101:15 C013/1

I2.7 -A102/CH23 LOCAL_STOP_PB-S101 X101:18 C014/1

I3.0 -A102/CH24 DI_SPARE_01 SPARESPARE/NO FIELD TERM -/-

I3.1 -A102/CH25 DI_SPARE_02 SPARESPARE/NO FIELD TERM -/-

I3.2 -A102/CH26 DI_SPARE_03 SPARESPARE/NO FIELD TERM -/-

I3.3 -A102/CH27 DI_SPARE_04 SPARESPARE/NO FIELD TERM -/-

I3.4 -A102/CH28 DI_SPARE_05 SPARESPARE/NO FIELD TERM -/-

I3.5 -A102/CH29 DI_SPARE_06 SPARESPARE/NO FIELD TERM -/-

I3.6 -A102/CH30 DI_SPARE_07 SPARESPARE/NO FIELD TERM -/-

I3.7 -A102/CH31 DI_SPARE_08 SPARESPARE/NO FIELD TERM -/-

FICTIONAL ENGINEERINGPROJECT - NOT FOR CONSTRUCTION

CONCEPTUALSAFETYARCHITECTURE- REQUIRESPROJECT-SPECIFIC RISKASSESSMENT,DESIGN,VERIFICATION AND VALIDATION BYAQUALIFIED MACHINERY-SAFETYENGINEER.NOPERFORMANCELEVEL,SIL,CATEGORY,CECONFORMITYOR REGULATORYCOMPLIANCEISCLAIMED.

A

B

C

D

E

F

# Author: FC01 engineering team PLC digital outputs Q0.0-Q1.7

# File: FC01_revision_e.qet

# E-10 PLC DIGITAL OUTPUTS Q0.0-Q1.7

## RREEVV EE || 1100//2266

Q0.0 -A103/CH0 DO_SPARE_DRIVE_REMOVED_01 SPARESPARE/NO FIELD TERM -/-

Q0.1 -A103/CH1 DO_SPARE_DRIVE_REMOVED_02 SPARESPARE/NO FIELD TERM -/-

Q0.2 -A103/CH2 FILL_VALVE_1_OPEN_CMD -K202 X101:21 C015/1

Q0.3 -A103/CH3 FILL_VALVE_2_OPEN_CMD -K203 X101:23 C016/1

Q0.4 -A103/CH4 GATE_OPEN_CMD -K204 X102:1 C017/1

Q0.5 -A103/CH5 GATE_CLOSE_CMD -K205 X102:3 C017/3

Q0.6 -A103/CH6 CLAMP_ENGAGE_CMD -K206 X102:5 C018/1

Q0.7 -A103/CH7 CLAMP_RELEASE_CMD -K207 X102:7 C018/3

Q1.0 -A103/CH8 CAPPER_REQUEST -K208 X102:9 C012/7

Q1.1 -A103/CH9 STACK_GREEN -K209 X102:11 C019/1

Q1.2 -A103/CH10 STACK_AMBER -K210 X102:13 C019/3

Q1.3 -A103/CH11 STACK_RED -K211 X102:15 C019/5

Q1.4 -A103/CH12 AUDIBLE_ALARM -K212 X102:17 C019/7

Q1.5 -A103/CH13 CAMERA_LIGHT_ENABLE-K213 X102:19 C020/1

Q1.6 -A103/CH14 DO_SPARE_01 SPARESPARE/NO FIELD TERM -/-

Q1.7 -A103/CH15 DO_SPARE_02 SPARESPARE/NO FIELD TERM -/-

FICTIONAL ENGINEERINGPROJECT - NOT FOR CONSTRUCTION

CONCEPTUALSAFETYARCHITECTURE- REQUIRESPROJECT-SPECIFIC RISKASSESSMENT,DESIGN,VERIFICATION AND VALIDATION BYAQUALIFIED MACHINERY-SAFETYENGINEER.NOPERFORMANCELEVEL,SIL,CATEGORY,CECONFORMITYOR REGULATORYCOMPLIANCEISCLAIMED.

A

B

C

D

E

F

# Author: FC01 engineering team PLC digital outputs Q2.0-Q3.7 and spares

# File: FC01_revision_e.qet

# E-11 PLC DIGITAL OUTPUTS Q2.0-Q3.7 AND SPARES

## RREEVV EE || 1111//2266

Q2.0 -A103/CH16 DO_SPARE_03 SPARESPARE/NO FIELD TERM -/-

Q2.1 -A103/CH17 DO_SPARE_04 SPARESPARE/NO FIELD TERM -/-

Q2.2 -A103/CH18 DO_SPARE_05 SPARESPARE/NO FIELD TERM -/-

Q2.3 -A103/CH19 DO_SPARE_06 SPARESPARE/NO FIELD TERM -/-

Q2.4 -A103/CH20 DO_SPARE_07 SPARESPARE/NO FIELD TERM -/-

Q2.5 -A103/CH21 DO_SPARE_08 SPARESPARE/NO FIELD TERM -/-

Q2.6 -A103/CH22 DO_SPARE_09 SPARESPARE/NO FIELD TERM -/-

Q2.7 -A103/CH23 DO_SPARE_10 SPARESPARE/NO FIELD TERM -/-

Q3.0 -A103/CH24 DO_SPARE_11 SPARESPARE/NO FIELD TERM -/-

Q3.1 -A103/CH25 DO_SPARE_12 SPARESPARE/NO FIELD TERM -/-

Q3.2 -A103/CH26 DO_SPARE_13 SPARESPARE/NO FIELD TERM -/-

Q3.3 -A103/CH27 DO_SPARE_14 SPARESPARE/NO FIELD TERM -/-

Q3.4 -A103/CH28 DO_SPARE_15 SPARESPARE/NO FIELD TERM -/-

Q3.5 -A103/CH29 DO_SPARE_16 SPARESPARE/NO FIELD TERM -/-

Q3.6 -A103/CH30 DO_SPARE_17 SPARESPARE/NO FIELD TERM -/-

Q3.7 -A103/CH31 DO_SPARE_18 SPARESPARE/NO FIELD TERM -/-

FICTIONAL ENGINEERINGPROJECT - NOT FOR CONSTRUCTION

CONCEPTUALSAFETYARCHITECTURE- REQUIRESPROJECT-SPECIFIC RISKASSESSMENT,DESIGN,VERIFICATION AND VALIDATION BYAQUALIFIED MACHINERY-SAFETYENGINEER.NOPERFORMANCELEVEL,SIL,CATEGORY,CECONFORMITYOR REGULATORYCOMPLIANCEISCLAIMED.

A

B

C

D

E

F

# Author: FC01 engineering team Analog inputs and shield termination

# File: FC01_revision_e.qet

E-12 ANALOG INPUTS AND SHIELD TERMINATION | RREEVV EE || 1122//2266

IW64 -A104/CH0 FLOW_1_MA_RAW -FT100 X102:21 C021/1

IW66 -A104/CH1 FLOW_2_MA_RAW -FT101 X103:1 C022/1

IW68 -A104/CH2 AI_SPARE_01 SPARESPARE/NO FIELD TERM -/-

IW70 -A104/CH3 AI_SPARE_02 SPARESPARE/NO FIELD TERM -/-

IW72 -A104/CH4 AI_SPARE_03 SPARESPARE/NO FIELD TERM -/-

IW74 -A104/CH5 AI_SPARE_04 SPARESPARE/NO FIELD TERM -/-

IW76 -A104/CH6 AI_SPARE_05 SPARESPARE/NO FIELD TERM -/-

IW78 -A104/CH7 AI_SPARE_06 SPARESPARE/NO FIELD TERM -/-

FT100/FT101 are 4-20 mA channels; overall shields/drains terminate at SC100 on the panel end only unless the final EMC study requires otherwise.

AI spare channels are uncommitted. Final MANA grouping, transmitter isolation and fault-range behavior require native configuration.

FICTIONAL ENGINEERINGPROJECT - NOT FOR CONSTRUCTION

CONCEPTUALSAFETYARCHITECTURE- REQUIRESPROJECT-SPECIFIC RISKASSESSMENT,DESIGN,VERIFICATION AND VALIDATION BYAQUALIFIED MACHINERY-SAFETYENGINEER.NOPERFORMANCELEVEL,SIL,CATEGORY,CECONFORMITYOR REGULATORYCOMPLIANCEISCLAIMED.

A

B

C

D

E

F

# Author: FC01 engineering team TM Count high-speed pulse inputs

# File: FC01_revision_e.qet

SENSOR /INSTRUMENT | PLC /MODULE | SENSOR /INSTRUMENT

# E-13 TM COUNT HIGH-SPEED PULSE INPUTS

## RREEVV EE || 1133//2266

## =FC01+FLD-FT100

### Flowmeter pulse channel 1

C021 core 4 to TM1.CH0.A

## =FC01+CP01-A101

### TM Count 2x24V

CH0 A/CH1 A

## =FC01+FLD-FT101

### Flowmeter pulse channel 2

C022 core 4 to TM1.CH1.A

TM1.CH0.A-A101/CHCH0 AFLOW_1_PULSE-FT100 X103:5 C021/4

TM1.CH1.A-A101/CHCH1 AFLOW_2_PULSE-FT101 X103:7 C022/4

Pulse and 4-20 mA signals are independent diagnostics from each flowmeter; neither substitutes for the other.

FICTIONAL ENGINEERINGPROJECT - NOT FOR CONSTRUCTION

CONCEPTUALSAFETYARCHITECTURE- REQUIRESPROJECT-SPECIFIC RISKASSESSMENT,DESIGN,VERIFICATION AND VALIDATION BYAQUALIFIED MACHINERY-SAFETYENGINEER.NOPERFORMANCELEVEL,SIL,CATEGORY,CECONFORMITYOR REGULATORYCOMPLIANCEISCLAIMED.

A

B

C

D

E

F

# Author: FC01 engineering team Conveyor G120C power and PROFINET control

# File: FC01_revision_e.qet

PROTECTIVEDEVICE | VARIABLE-FREQUENCYDRIVE | MOTOR | TERMINAL /SHIELD

# E-14 CONVEYOR G120C POWER AND PROFINET CONTROL

## RREEVV EE || 1144//2266

## =FC01+CP01-QF100

### Provisional drive branch protection

## =FC01+CP01-U100

### G120C PN conveyor drive

Standard Telegram 1;IW/QW256-259

## =FC01+FLD-M100

### Conveyor motor

Nameplate and duty open

## =FC01+CP01-PE100

### Motor PE/bonding

PLC controls STW1 and speed reference; drive returns ZSW1 and actual speed. No hardwired ordinary run/ready path is claimed.

External STO is conceptual safety scope and is not controlled or credited by the standard PLC.

FICTIONAL ENGINEERINGPROJECT - NOT FOR CONSTRUCTION

CONCEPTUALSAFETYARCHITECTURE- REQUIRESPROJECT-SPECIFIC RISKASSESSMENT,DESIGN,VERIFICATION AND VALIDATION BYAQUALIFIED MACHINERY-SAFETYENGINEER.NOPERFORMANCELEVEL,SIL,CATEGORY,CECONFORMITYOR REGULATORYCOMPLIANCEISCLAIMED.

A

B

C

D

E

F

# Author: FC01 engineering team Pump G120C power and PROFINET control

# File: FC01_revision_e.qet

PROTECTIVEDEVICE | VARIABLE-FREQUENCYDRIVE | MOTOR | TERMINAL /SHIELD

# E-15 PUMP G120C POWER AND PROFINET CONTROL

## RREEVV EE || 1155//2266

## =FC01+CP01-QF100

### Provisional drive branch protection

## =FC01+CP01-U101

### G120C PN dosing-pump drive

Standard Telegram 1;IW/QW260-263

## =FC01+FLD-M101

### Pump motor

Nameplate and hydraulic duty open

## =FC01+CP01-PE100

### Motor PE/bonding

Pump speed, ramps, current limits and overload duty remain provisional until motor and pump nameplates and process duty are supplied.

External STO is conceptual safety scope and is not controlled or credited by the standard PLC.

FICTIONAL ENGINEERINGPROJECT - NOT FOR CONSTRUCTION

CONCEPTUALSAFETYARCHITECTURE- REQUIRESPROJECT-SPECIFIC RISKASSESSMENT,DESIGN,VERIFICATION AND VALIDATION BYAQUALIFIED MACHINERY-SAFETYENGINEER.NOPERFORMANCELEVEL,SIL,CATEGORY,CECONFORMITYOR REGULATORYCOMPLIANCEISCLAIMED.

A

B

C

D

E

F

# Author: FC01 engineering team Motor cables, PE and shield termination

# File: FC01_revision_e.qet

VARIABLE-FREQUENCYDRIVE | TERMINAL /SHIELD | MOTOR | VARIABLE-FREQUENCYDRIVE | MOTOR
E-16 MOTOR CABLES, PE AND SHIELD TERMINATION | RREEVV EE || 1166//2266

## =FC01+CP01-U100

### Conveyor drive

## =FC01+CP01-SC100

### 360-degree shield-clamp rail

## =FC01+FLD-M100

### Conveyor motor

## =FC01+CP01-U101

### Pump drive

## =FC01+FLD-M101

### Pump motor

W901 denotes the controlled requirement for shielded VFD motor cables and EMC termination kits; exact cable identifiers and routes remain open.

Maintain short, low-impedance shield terminations and continuous PE. Final routing, ampacity and EMC checks require installed geometry.

FICTIONAL ENGINEERINGPROJECT - NOT FOR CONSTRUCTION

CONCEPTUALSAFETYARCHITECTURE- REQUIRESPROJECT-SPECIFIC RISKASSESSMENT,DESIGN,VERIFICATION AND VALIDATION BYAQUALIFIED MACHINERY-SAFETYENGINEER.NOPERFORMANCELEVEL,SIL,CATEGORY,CECONFORMITYOR REGULATORYCOMPLIANCEISCLAIMED.

A

# E-17 PROFINET AND OT NETWORK ARCHITECTURE

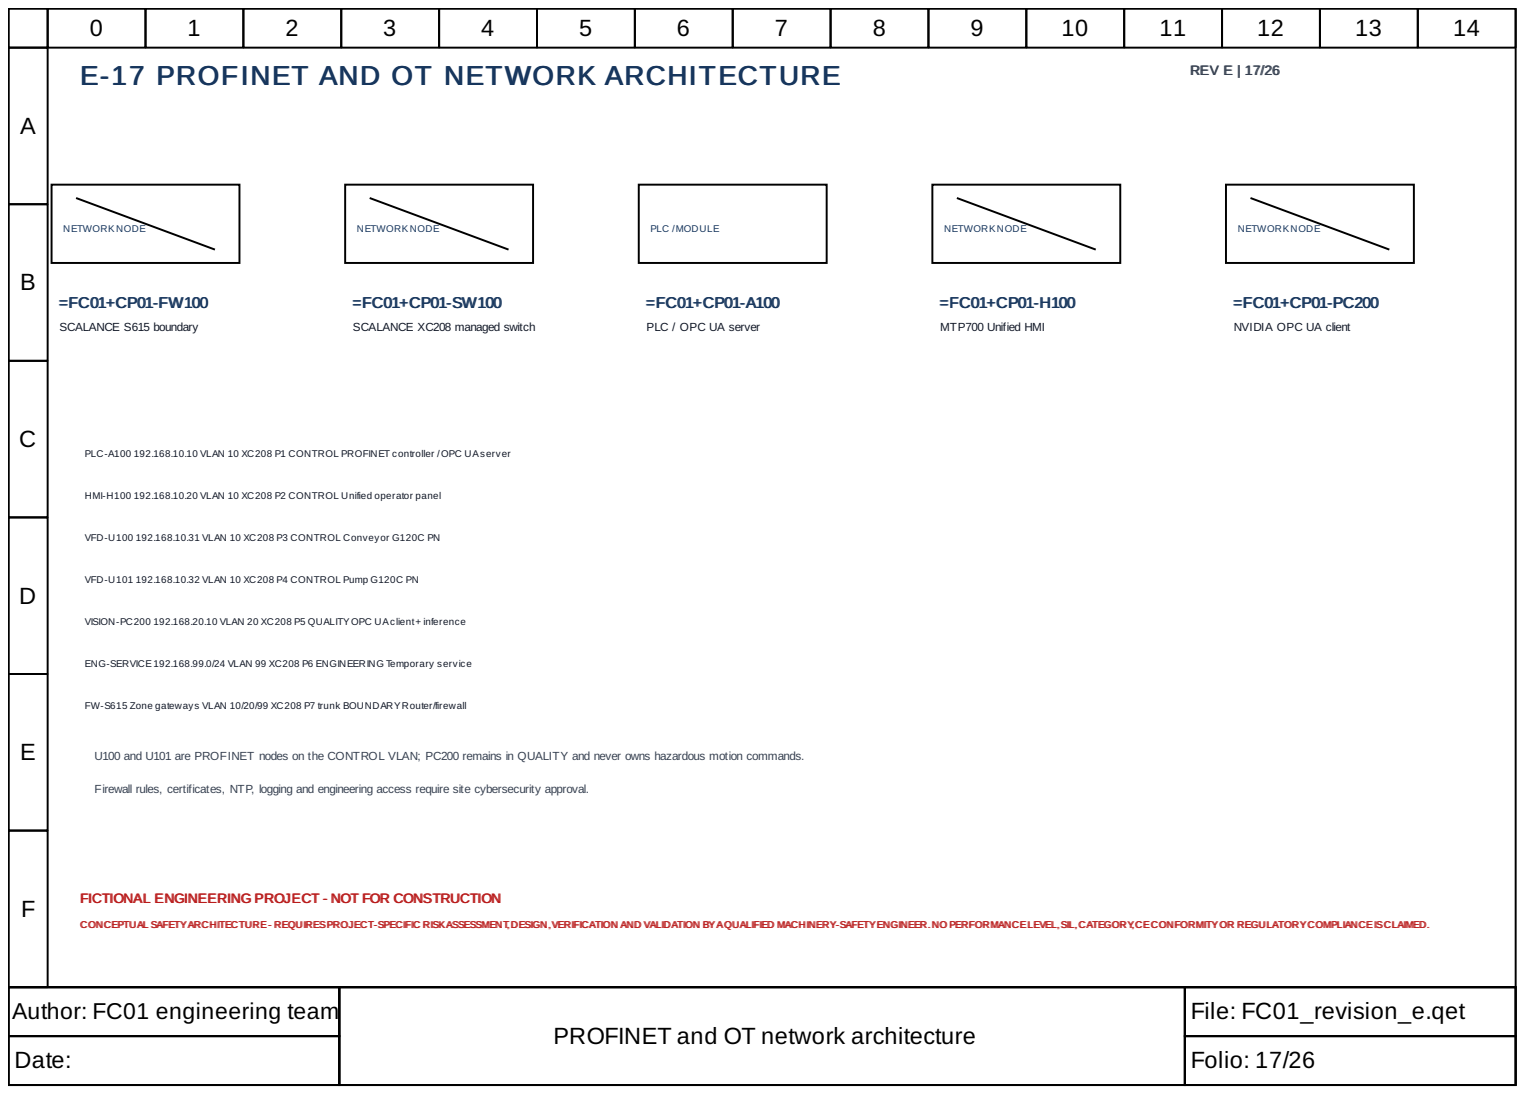
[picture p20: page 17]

PLC / OPC UA server

NVIDIA OPC UA client

PLC-A100 192.168.10.10 VLAN 10 XC208 P1 CONTROL PROFINET controller /OPC UAserver

HMI-H100 192.168.10.20 VLAN 10 XC208 P2 CONTROL Unified operator panel

VFD-U100 192.168.10.31 VLAN 10 XC208 P3 CONTROL Conveyor G120C PN

VFD-U101 192.168.10.32 VLAN 10 XC208 P4 CONTROL Pump G120C PN

VISION-PC200 192.168.20.10 VLAN 20 XC208 P5 QUALITYOPC UAclient+ inference

ENG-SERVICE192.168.99.0/24 VLAN 99 XC208 P6 ENGINEERING Temporary service

FW-S615 Zone gateways VLAN 10/20/99 XC208 P7 trunk BOUNDARYRouter/firewall

U100 and U101 are PROFINET nodes on the CONTROL VLAN; PC200 remains in QUALITY and never owns hazardous motion commands.

Firewall rules, certificates, NTP, logging and engineering access require site cybersecurity approval.

FICTIONAL ENGINEERINGPROJECT - NOT FOR CONSTRUCTION

CONCEPTUALSAFETYARCHITECTURE- REQUIRESPROJECT-SPECIFIC RISKASSESSMENT,DESIGN,VERIFICATION AND VALIDATION BYAQUALIFIED MACHINERY-SAFETYENGINEER.NOPERFORMANCELEVEL,SIL,CATEGORY,CECONFORMITYOR REGULATORYCOMPLIANCEISCLAIMED.

PROFINET and OT network architecture

A

B

C

D

E

F

# Author: FC01 engineering team HMI and NVIDIAinspection interface

# File: FC01_revision_e.qet

NETWORKNODE | PLC /MODULE | NETWORKNODE | SENSOR /INSTRUMENT | ACTUATOR /RELAY

# E-18 HMI AND NVIDIA INSPECTION INTERFACE

## RREEVV EE || 1188//2266

## =FC01+CP01-H100

### MTP700 Unified Comfort

## =FC01+CP01-A100

### Sequence and interlock authority

## =FC01+CP01-PC200

### Non-safety quality inspection

## =FC01+FLD-CAM200

### Industrial camera

## =FC01+FLD-LT200

### Controlled vision lighting

OPC UA transaction uses nonzero session/inspection identity, held request handshake, immutable result publication and exact acknowledgement.

Missing, stale, duplicate, contradictory, uncertain, model-mismatched or timed-out AI data produces deterministic HOLD or reject disposition.

NVIDIA cannot command physical outputs, drives, sequence transitions or bypass PLC interlocks.

FICTIONAL ENGINEERINGPROJECT - NOT FOR CONSTRUCTION

CONCEPTUALSAFETYARCHITECTURE- REQUIRESPROJECT-SPECIFIC RISKASSESSMENT,DESIGN,VERIFICATION AND VALIDATION BYAQUALIFIED MACHINERY-SAFETYENGINEER.NOPERFORMANCELEVEL,SIL,CATEGORY,CECONFORMITYOR REGULATORYCOMPLIANCEISCLAIMED.

A

B

C

D

E

F

# Author: FC01 engineering team Solenoid valves and interposing relays

# File: FC01_revision_e.qet

PLC /MODULE | ACTUATOR /RELAY | ACTUATOR /RELAY | ACTUATOR /RELAY | ACTUATOR /RELAY

ACTUATOR /RELAY

# E-19 SOLENOID VALVES AND INTERPOSING RELAYS

## RREEVV EE || 1199//2266

## =FC01+CP01-A103

### DQ 32x24V DC

## =FC01+CP01-K202..-K213

### Interposing relay family

## =FC01+FLD-YV100

### Gate solenoid

C017

## =FC01+FLD-YV101

### Clamp solenoid

C018

## =FC01+FLD-YV102

### Fill valve 1 fail closed

C015

## =FC01+FLD-YV103

### Fill valve 2 fail closed

C016

K202-K213 relay coils require D202-D213 suppression. Gate/clamp opposing commands are interlocked in PLC logic.

Fill valves are fail closed; de-energized state is closed. Final coil current and protection coordination remain open.

FICTIONAL ENGINEERINGPROJECT - NOT FOR CONSTRUCTION

CONCEPTUALSAFETYARCHITECTURE- REQUIRESPROJECT-SPECIFIC RISKASSESSMENT,DESIGN,VERIFICATION AND VALIDATION BYAQUALIFIED MACHINERY-SAFETYENGINEER.NOPERFORMANCELEVEL,SIL,CATEGORY,CECONFORMITYOR REGULATORYCOMPLIANCEISCLAIMED.

A

B

C

D

E

F

# Author: FC01 engineering team Field sensors, flow and level instrumentation

# File: FC01_revision_e.qet

SENSOR /INSTRUMENT | SENSOR /INSTRUMENT | SENSOR /INSTRUMENT | SENSOR /INSTRUMENT | SENSOR /INSTRUMENT
SENSOR /INSTRUMENT | SENSOR /INSTRUMENT | SENSOR /INSTRUMENT | SENSOR /INSTRUMENT | SENSOR /INSTRUMENT
E-20 FIELD SENSORS, FLOW AND LEVEL INSTRUMENTATION | RREEVV EE || 2200//2266

## =FC01+FLD-B100

### Air pressure switch

## =FC01+FLD-B101

### Product supply permissive

## =FC01+FLD-B110

### Bottle nest 1

## =FC01+FLD-B111

### Bottle nest 2

## =FC01+FLD-FT100

### Flow channel 1 pulse + 4-20 mA

## =FC01+FLD-FT101

### Flow channel 2 pulse + 4-20 mA

## =FC01+FLD-B120

### Gate open proof

## =FC01+FLD-B121

### Gate closed proof

## =FC01+FLD-B122

### Clamp released proof

## =FC01+FLD-B123

### Clamp engaged proof

B130/B131 provide fill-valve closed proof; LT200 is vision lighting, not a process-level transmitter.

All ordinary sensing is non-safety unless separately designed and validated by a qualified machinery-safety engineer.

FICTIONAL ENGINEERINGPROJECT - NOT FOR CONSTRUCTION

CONCEPTUALSAFETYARCHITECTURE- REQUIRESPROJECT-SPECIFIC RISKASSESSMENT,DESIGN,VERIFICATION AND VALIDATION BYAQUALIFIED MACHINERY-SAFETYENGINEER.NOPERFORMANCELEVEL,SIL,CATEGORY,CECONFORMITYOR REGULATORYCOMPLIANCEISCLAIMED.

A

B

C

D

E

F

# Author: FC01 engineering team Stack light, local stations and capper interface

# File: FC01_revision_e.qet

DEVICE | DEVICE | ACTUATOR /RELAY | TERMINAL /SHIELD | PLC /MODULE

PLC /MODULE

# E-21 STACK LIGHT, LOCAL STATIONS AND CAPPER INTERFACE

## RREEVV EE || 2211//2266

## =FC01+FLD-S100

### Local reset pushbutton

C013

## =FC01+FLD-S101

### Local controlled-stop pushbutton

C014

## =FC01+FLD-H101

### Three-color stack light and sounder

C019

## =FC01+FLD-IF140

### Capper ready/busy/complete/fault/request

C012

## =FC01+CP01-A102

### DI capper/local feedback

## =FC01+CP01-A103

### DO request/indication

Capper BUSY/COMPLETE is accepted only after a correlated request. Unsolicited status is a deterministic interface fault.

Local stop is a controlled process stop, not an emergency-stop or protective device.

FICTIONAL ENGINEERINGPROJECT - NOT FOR CONSTRUCTION

CONCEPTUALSAFETYARCHITECTURE- REQUIRESPROJECT-SPECIFIC RISKASSESSMENT,DESIGN,VERIFICATION AND VALIDATION BYAQUALIFIED MACHINERY-SAFETYENGINEER.NOPERFORMANCELEVEL,SIL,CATEGORY,CECONFORMITYOR REGULATORYCOMPLIANCEISCLAIMED.

A

B

C

D

E

F

# Author: FC01 engineering team Terminal strips X100 and X101

# File: FC01_revision_e.qet

# E-22 TERMINAL STRIPS X100 AND X101

## RREEVV EE || 2222//2266

X100:1 GUARD_CLOSED_STATUS C001 /1 I0.1 24 VDC switched W0003

X100:2 GUARD_CLOSED_STATUS C001 /2 I0.1 +24VDC fused W0004

X100:3 AIR_PRESSURE_OK C002 /1 I0.2 24 VDC switched W0005

X100:4 AIR_PRESSURE_OK C002 /2 I0.2 +24VDC fused W0006

X100:5 AIR_PRESSURE_OK C002 /3 I0.2 0V W0007

X100:6 PRODUCT_SUPPLY_OK C003 /1 I0.3 24 VDC switched W0008

X100:7 PRODUCT_SUPPLY_OK C003 /2 I0.3 +24VDC fused W0009

X100:8 PRODUCT_SUPPLY_OK C003 /3 I0.3 0V W0010

X100:9 BOTTLE_AT_NEST_1 C004 /1 I1.2 24 VDC switched W0011

X100:10 BOTTLE_AT_NEST_1 C004 /2 I1.2 +24VDC fused W0012

X100:11 BOTTLE_AT_NEST_1 C004 /3 I1.2 0V W0013

X100:12 BOTTLE_AT_NEST_2 C005 /1 I1.3 24 VDC switched W0014

X100:13 BOTTLE_AT_NEST_2 C005 /2 I1.3 +24VDC fused W0015

X100:14 BOTTLE_AT_NEST_2 C005 /3 I1.3 0V W0016

X100:15 GATE_OPEN_FB C006 /1 I1.4 24 VDC switched W0017

X100:16 GATE_OPEN_FB C006 /2 I1.4 +24VDC fused W0018

X100:17 GATE_OPEN_FB C006 /3 I1.4 0V W0019

X100:18 GATE_CLOSED_FB C007 /1 I1.5 24 VDC switched W0020

X100:19 GATE_CLOSED_FB C007 /2 I1.5 +24VDC fused W0021

X100:20 GATE_CLOSED_FB C007 /3 I1.5 0V W0022

X100:21 CLAMP_RELEASED_FB C008 /1 I1.6 24 VDC switched W0023

X100:22 CLAMP_RELEASED_FB C008 /2 I1.6 +24VDC fused W0024

X100:23 CLAMP_RELEASED_FB C008 /3 I1.6 0V W0025

X100:24 CLAMP_ENGAGED_FB C009 /1 I1.7 24 VDC switched W0026

X101:1 CLAMP_ENGAGED_FB C009 /2 I1.7 +24VDC fused W0027

X101:2 CLAMP_ENGAGED_FB C009 /3 I1.7 0V W0028

X101:3 FILL_VALVE_1_CLOSED_FB C010 /1 I2.0 24 VDC switched W0029

X101:4 FILL_VALVE_1_CLOSED_FB C010 /2 I2.0 +24VDC fused W0030

X101:5 FILL_VALVE_1_CLOSED_FB C010 /3 I2.0 0V W0031

X101:6 FILL_VALVE_2_CLOSED_FB C011 /1 I2.1 24 VDC switched W0032

X101:7 FILL_VALVE_2_CLOSED_FB C011 /2 I2.1 +24VDC fused W0033

X101:8 FILL_VALVE_2_CLOSED_FB C011 /3 I2.1 0V W0034

X101:9 CAPPER_READY C012 /1 I2.2 24 VDC switched W0035

X101:10 CAPPER_READY C012 /2 I2.2 +24VDC fused W0036

X101:11 CAPPER_READY C012 /3 I2.2 0V W0037

X101:12 CAPPER_BUSY C012 /4 I2.3 24 VDC switched W0038

X101:13 CAPPER_COMPLETE C012 /5 I2.4 24 VDC switched W0039

X101:14 CAPPER_FAULTC012 /6 I2.5 24 VDC switched W0040

X101:15 LOCAL_RESET_PB C013 /1 I2.6 24 VDC switched W0041

X101:16 LOCAL_RESET_PB C013 /2 I2.6 +24VDC fused W0042

X101:17 LOCAL_RESET_PB C013 /3 I2.6 0V W0043

X101:18 LOCAL_STOP_PB C014 /1 I2.7 24 VDC switched W0044

X101:19 LOCAL_STOP_PB C014 /2 I2.7 +24VDC fused W0045

X101:20 LOCAL_STOP_PB C014 /3 I2.7 0V W0046

X101:21 FILL_VALVE_1_OPEN_CMD C015 /1 Q0.2 +24VDC switched W0050

X101:22 FILL_VALVE_1_OPEN_CMD C015 /2 Q0.2 0V W0051

X101:23 FILL_VALVE_2_OPEN_CMD C016 /1 Q0.3 +24VDC switched W0055

X101:24 FILL_VALVE_2_OPEN_CMD C016 /2 Q0.3 0V W0056

FICTIONAL ENGINEERINGPROJECT - NOT FOR CONSTRUCTION

CONCEPTUALSAFETYARCHITECTURE- REQUIRESPROJECT-SPECIFIC RISKASSESSMENT,DESIGN,VERIFICATION AND VALIDATION BYAQUALIFIED MACHINERY-SAFETYENGINEER.NOPERFORMANCELEVEL,SIL,CATEGORY,CECONFORMITYOR REGULATORYCOMPLIANCEISCLAIMED.

A

B

C

D

E

F

# Author: FC01 engineering team Terminal strips X102/X103, power, common and shields

# File: FC01_revision_e.qet

# E-23 TERMINAL STRIPS X102/X103, POWER, COMMON AND SHIELDS

## RREEVV EE || 2233//2266

X102:1 GATE_OPEN_CMD C017 /1 Q0.4 +24VDC switched W0060

X102:2 GATE_OPEN_CMD C017 /2 Q0.4 0V W0061

X102:3 GATE_CLOSE_CMD C017 /3 Q0.5 +24VDC switched W0065

X102:4 GATE_CLOSE_CMD C017 /4 Q0.5 0V W0066

X102:5 CLAMP_ENGAGE_CMD C018 /1 Q0.6 +24VDC switched W0070

X102:6 CLAMP_ENGAGE_CMD C018 /2 Q0.6 0V W0071

X102:7 CLAMP_RELEASE_CMD C018 /3 Q0.7 +24VDC switched W0075

X102:8 CLAMP_RELEASE_CMD C018 /4 Q0.7 0V W0076

X102:9 CAPPER_REQUESTC012 /7 Q1.0 +24VDC switched W0080

X102:10 CAPPER_REQUESTC012 /8 Q1.0 0V W0081

X102:11 STACK_GREEN C019 /1 Q1.1 +24VDC switched W0085

X102:12 STACK_GREEN C019 /2 Q1.1 0V W0086

X102:13 STACK_AMBER C019 /3 Q1.2 +24VDC switched W0090

X102:14 STACK_AMBER C019 /4 Q1.2 0V W0091

X102:15 STACK_RED C019 /5 Q1.3 +24VDC switched W0095

X102:16 STACK_RED C019 /6 Q1.3 0V W0096

X102:17 AUDIBLE_ALARM C019 /7 Q1.4 +24VDC switched W0100

X102:18 AUDIBLE_ALARM C019 /8 Q1.4 0V W0101

X102:19 CAMERA_LIGHT_ENABLE C020 /1 Q1.5 +24VDC switched W0105

X102:20 CAMERA_LIGHT_ENABLE C020 /2 Q1.5 0V W0106

X102:21 FLOW_1_MA_RAW C021 /1 IW64 4-20mA W0107

X102:22 FLOW_1_MA_RAW C021 /2 IW64 +24VDC fused W0108

X102:23 FLOW_1_MA_RAW C021 /3 IW64 0V analog W0109

X102:24 FLOW_1_MA_RAW C021 /SH IW64 FE W0110

X103:1 FLOW_2_MA_RAW C022 /1 IW66 4-20mA W0111

X103:2 FLOW_2_MA_RAW C022 /2 IW66 +24VDC fused W0112

X103:3 FLOW_2_MA_RAW C022 /3 IW66 0V analog W0113

X103:4 FLOW_2_MA_RAW C022 /SH IW66 FE W0114

X103:5 FLOW_1_PULSE C021 /4 TM1.CH0.A 24 V pulse W0115

X103:6 FLOW_1_PULSE C021 /5 TM1.CH0.A 0V W0116

X103:7 FLOW_2_PULSE C022 /4 TM1.CH1.A 24 V pulse W0117

X103:8 FLOW_2_PULSE C022 /5 TM1.CH1.A 0V W0118

X24:+24V X24:+24V - /- - +24VDC

X0:0V X0:0V - /- - 0V

X0:MANA X0:MANA - /- - 0V analog

SC100:1 SC100:1 - /- - FE

FICTIONAL ENGINEERINGPROJECT - NOT FOR CONSTRUCTION

CONCEPTUALSAFETYARCHITECTURE- REQUIRESPROJECT-SPECIFIC RISKASSESSMENT,DESIGN,VERIFICATION AND VALIDATION BYAQUALIFIED MACHINERY-SAFETYENGINEER.NOPERFORMANCELEVEL,SIL,CATEGORY,CECONFORMITYOR REGULATORYCOMPLIANCEISCLAIMED.

A

B

C

D

E

F

# Author: FC01 engineering team Cable schedule and external field connections

# File: FC01_revision_e.qet

# E-24 CABLE SCHEDULE AND EXTERNAL FIELD CONNECTIONS

## RREEVV EE || 2244//2266

C001 =FC01+CP01 panel terminals -> =FC01+FLD-S102 Industrial control cores 2/4 None scheduled 24 VDC control

C002 =FC01+CP01 panel terminals -> =FC01+FLD-B100 Industrial control cores 3/4 None scheduled 24 VDC control

C003 =FC01+CP01 panel terminals -> =FC01+FLD-B101 Industrial control cores 3/4 None scheduled 24 VDC control

C004 =FC01+CP01 panel terminals -> =FC01+FLD-B110 Industrial control cores 3/4 None scheduled 24 VDC control

C005 =FC01+CP01 panel terminals -> =FC01+FLD-B111 Industrial control cores 3/4 None scheduled 24 VDC control

C006 =FC01+CP01 panel terminals -> =FC01+FLD-B120 Industrial control cores 3/4 None scheduled 24 VDC control

C007 =FC01+CP01 panel terminals -> =FC01+FLD-B121 Industrial control cores 3/4 None scheduled 24 VDC control

C008 =FC01+CP01 panel terminals -> =FC01+FLD-B122 Industrial control cores 3/4 None scheduled 24 VDC control

C009 =FC01+CP01 panel terminals -> =FC01+FLD-B123 Industrial control cores 3/4 None scheduled 24 VDC control

C010 =FC01+CP01 panel terminals -> =FC01+FLD-B130 Industrial control cores 3/4 None scheduled 24 VDC control

C011 =FC01+CP01 panel terminals -> =FC01+FLD-B131 Industrial control cores 3/4 None scheduled 24 VDC control

C012 =FC01+CP01 panel terminals -> =FC01+FLD-IF140 Industrial control cores 8/12 None scheduled 24 VDC control

C013 =FC01+CP01 panel terminals -> =FC01+FLD-S100 Industrial control cores 3/4 None scheduled 24 VDC control

C014 =FC01+CP01 panel terminals -> =FC01+FLD-S101 Industrial control cores 3/4 None scheduled 24 VDC control

C015 =FC01+CP01 panel terminals -> =FC01+FLD-YV102 Industrial control cores 2/4 None scheduled 24 VDC control

C016 =FC01+CP01 panel terminals -> =FC01+FLD-YV103 Industrial control cores 2/4 None scheduled 24 VDC control

C017 =FC01+CP01 panel terminals -> =FC01+FLD-YV100 Industrial control cores 4/8 None scheduled 24 VDC control

C018 =FC01+CP01 panel terminals -> =FC01+FLD-YV101 Industrial control cores 4/8 None scheduled 24 VDC control

C019 =FC01+CP01 panel terminals -> =FC01+FLD-H101 Industrial control cores 8/12 None scheduled 24 VDC control

C020 =FC01+CP01 panel terminals -> =FC01+FLD-LT200 Industrial control cores 2/4 None scheduled 24 VDC control

C021 =FC01+CP01 panel terminals -> =FC01+FLD-FT100 Shielded instrumentation cores 5/8 Separate overall shield/drain to SC100; not counted as an insulated core Analog/instrument

C022 =FC01+CP01 panel terminals -> =FC01+FLD-FT101 Shielded instrumentation cores 5/8 Separate overall shield/drain to SC100; not counted as an insulated core Analog/instrument

Cable/core identifiers on this folio are copied from the controlled schedule; conductor sizes remain blank pending site and installation data.

C021/C022 instrumentation shields terminate at SC100. Power and VFD motor cables remain open schedule inputs.

FICTIONAL ENGINEERINGPROJECT - NOT FOR CONSTRUCTION

CONCEPTUALSAFETYARCHITECTURE- REQUIRESPROJECT-SPECIFIC RISKASSESSMENT,DESIGN,VERIFICATION AND VALIDATION BYAQUALIFIED MACHINERY-SAFETYENGINEER.NOPERFORMANCELEVEL,SIL,CATEGORY,CECONFORMITYOR REGULATORYCOMPLIANCEISCLAIMED.

A

B

C

D

E

F

# Author: FC01 engineering team Conceptual safety interface and boundaries

# File: FC01_revision_e.qet

CONCEPTUAL SAFETYINTERFACE | CONCEPTUAL SAFETYINTERFACE | PLC /MODULE | VARIABLE-FREQUENCYDRIVE | VARIABLE-FREQUENCYDRIVE

# E-25 CONCEPTUAL SAFETY INTERFACE AND BOUNDARIES

## RREEVV EE || 2255//2266

## =FC01+FLD-S102

### Guard-status monitoring mirror

## =FC01+CP01-K100

### External safety-interface monitoring contact

## =FC01+CP01-A102

### Ordinary PLC status monitoring only

## =FC01+CP01-U100

### External STO conceptual interface

## =FC01+CP01-U101

### External STO conceptual interface

CONCEPTUAL SAFETY ARCHITECTURE - REQUIRES PROJECT-SPECIFIC RISK ASSESSMENT, DESIGN, VERIFICATION AND VALIDATION BY A QUALIFIED MACHINERY-SAFETY ENGINEER. NO PERFORMANCE LEVEL, SIL, CATEGORY, CE CONFORMITY OR REGULA

Standard PLC, HMI and NVIDIA functions receive status only and receive no safety credit.

OPEN: hazard analysis, protective-device selection, reset/restart design, PL/SIL/category determination and validation.

FICTIONAL ENGINEERINGPROJECT - NOT FOR CONSTRUCTION

CONCEPTUALSAFETYARCHITECTURE- REQUIRESPROJECT-SPECIFIC RISKASSESSMENT,DESIGN,VERIFICATION AND VALIDATION BYAQUALIFIED MACHINERY-SAFETYENGINEER.NOPERFORMANCELEVEL,SIL,CATEGORY,CECONFORMITYOR REGULATORYCOMPLIANCEISCLAIMED.

A

B

C

D

E

F

# Author: FC01 engineering team Spare capacity, BOM coverage and open inputs

# File: FC01_revision_e.qet

# E-26 SPARE CAPACITY, BOM COVERAGE AND OPEN INPUTS

## RREEVV EE || 2266//2266

=FC01+CP01-A100 SIMATIC S7-1500 CPU 1511-1 PN Selected baseline

=FC01+CP01-A101 TM Count 2x24V Selected baseline

=FC01+CP01-A102 DI 32x24V DC HFSelected baseline

=FC01+CP01-A103 DQ 32x24V DC/0.5A HFSelected baseline

=FC01+CP01-A104 AI 8xU/I HFSelected baseline

=FC01+CP01-H100 MTP700 Unified Comfort Selected baseline

=FC01+CP01-U100 SINAMICS G120C PN 0.75 kW unfiltered Provisional

=FC01+CP01-U101 SINAMICS G120C PN 0.75 kW unfiltered Provisional

=FC01+CP01-SW100 SCALANCE XC208 managed Selected network baseline

=FC01+CP01-FW100 SCALANCE S615 EEC Selected network baseline

=FC01+CP01-PC200 Jetson Orin NX 16GB on industrial carrier Architecture only

=FC01+CP01-MC100 SIMATIC memory card; capacity to be selected after compiled project sizing TBD

=FC01+CP01-RA100 S7-1500 mounting rail and fixing hardware TBD

=FC01+CP01-FC100 Front connector for DI module TBD

=FC01+CP01-FC101 Front connector for DQ module TBD

=FC01+CP01-FC102 Front connector for AI module TBD

=FC01+CP01-FC103 Front connector for TM Count module TBD

=FC01+CP01-QS100 Main door-coupled isolator TBD

=FC01+CP01-QF100 Main protective device TBD

=FC01+CP01-PS100 24 VDC 20 A power supply Provisional

=FC01+CP01-QF110 24 VDC electronic branch protection TBD

=FC01+CP01-K100 Main control enable contactor / external safety interface with dry monitoring contact TBD

=FC01+CP01-K202..-K213 Interposing relays with bases and status indication TBD

=FC01+CP01-D202..-D213 Coil suppression modules TBD

=FC01+CP01-X100..-X199 DIN-rail terminal blocks, disconnect/test where required Provisional quantity

=FC01+CP01-PE100 Copper protective-earth bar and bonding hardware TBD

=FC01+CP01-SC100 Shield-clamp rail and spring clamps Provisional quantity

=FC01+CP01-ENC100 IP-rated enclosure with mounting plate TBD

=FC01+CP01-WD100 Slotted wiring duct set TBD

=FC01+CP01-DR100 35 mm DIN rail set TBD

=FC01+FLD-GL100 Cable glands and EMC glands TBD

=FC01+CP01-FAN100 Filter fan / cooling solution TBD

=FC01+FLD-M100 Conveyor motor TBD

=FC01+FLD-M101 Pump motor TBD

=FC01+FLD-YV100 Gate valve/cylinder solenoid TBD

=FC01+FLD-YV101 Clamp valve/cylinder solenoid TBD

=FC01+FLD-YV102 Fill valve channel 1, fail closed TBD

=FC01+FLD-YV103 Fill valve channel 2, fail closed TBD

=FC01+FLD-FT100 Pulse plus 4-20 mA flowmeter channel 1 TBD

=FC01+FLD-FT101 Pulse plus 4-20 mA flowmeter channel 2 TBD

=FC01+FLD-S100 Local reset pushbutton TBD

=FC01+FLD-S101 Local controlled-stop pushbutton TBD

=FC01+FLD-S102 Guard-status dry-contact monitoring interface TBD

=FC01+FLD-H101 Three-color stack light with sounder TBD

=FC01+FLD-IF140 Capper interface terminals/relays TBD

=FC01+FLD-CAM200 Industrial camera TBD

=FC01+FLD-LENS200 C-mount lens TBD

=FC01+FLD-LT200 Machine-vision backlight/front-light assembly TBD

=FC01+FLD-CB200 Industrial Jetson carrier TBD

=FC01+FLD-W900 Industrial Ethernet patch cables/connectors Provisional quantity

=FC01+FLD-W901 Shielded VFD motor cables and EMC termination kits TBD

=FC01+FLD-CONS100 Markers, ferrules, lugs, ties and installation consumables TBD

=FC01+FLD-B100 Pneumatic pressure switch TBD

=FC01+FLD-B101 Product supply permissive TBD

=FC01+FLD-B110 Bottle 1 position sensor TBD

=FC01+FLD-B111 Bottle 2 position sensor TBD

=FC01+FLD-B120 Gate open feedback TBD

=FC01+FLD-B121 Gate closed feedback TBD

=FC01+FLD-B122 Clamp released feedback TBD

=FC01+FLD-B123 Clamp engaged feedback TBD

=FC01+FLD-B130 Valve 1 closed proof TBD

=FC01+FLD-B131 Valve 2 closed proof TBD

Controlled spare capacity: 8 DI, 18 DO and 6 AI allocated spares; spare terminals/cores require final allocation and labeling.

OPEN: supply/fault current, motor and pump data, cable routes, conductor sizing, thermal/EMC study, exact PC200 envelope and construction review.

FICTIONAL ENGINEERINGPROJECT - NOT FOR CONSTRUCTION

CONCEPTUALSAFETYARCHITECTURE- REQUIRESPROJECT-SPECIFIC RISKASSESSMENT,DESIGN,VERIFICATION AND VALIDATION BYAQUALIFIED MACHINERY-SAFETYENGINEER.NOPERFORMANCELEVEL,SIL,CATEGORY,CECONFORMITYOR REGULATORYCOMPLIANCEISCLAIMED.

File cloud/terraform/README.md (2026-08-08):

# Terraform operator boundary

> FICTIONAL ENGINEERING PROJECT - NOT FOR CONSTRUCTION.

> CONCEPTUAL SAFETY ARCHITECTURE - REQUIRES PROJECT-SPECIFIC RISK ASSESSMENT, DESIGN, VERIFICATION AND VALIDATION BY A QUALIFIED MACHINERY-SAFETY ENGINEER. NO PERFORMANCE LEVEL, SIL, CATEGORY, CE/UKCA CONFORMITY OR REGULATORY COMPLIANCE IS CLAIMED.

The module is reviewable source, not a recorded cloud plan. Both VM creation flags default to false. Copy the variable example outside Git, replace placeholders and authenticate with Application Default Credentials. Run `cloud/scripts/plan_cloud.ps1`; inspect every IAM, firewall, image, GPU, schedule, disk and budget change. Do not apply without separate explicit expenditure/security approval. Provider lock and saved plan files must not be committed if they contain project-sensitive data.

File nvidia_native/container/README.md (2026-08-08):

# Container build and rollback boundary

> FICTIONAL ENGINEERING PROJECT - NOT FOR CONSTRUCTION.

> CONCEPTUAL SAFETY ARCHITECTURE - REQUIRES PROJECT-SPECIFIC RISK ASSESSMENT, DESIGN, VERIFICATION AND VALIDATION BY A QUALIFIED MACHINERY-SAFETY ENGINEER. NO PERFORMANCE LEVEL, SIL, CATEGORY, CE/UKCA CONFORMITY OR REGULATORY COMPLIANCE IS CLAIMED.

No container was built in Revision G. From the repository root, after selecting an official compatible DeepStream image by immutable digest and approving network/package access, run:

`docker build --file nvidia_native/container/Dockerfile --build-arg BASE_IMAGE=<approved-registry/image@sha256:digest> --tag fc01-edge:<approved-version> .`

The adjacent `Dockerfile.dockerignore` limits the repository-root build context. Record the base digest, requirements hash, build command, image digest, SBOM and vulnerability report. Do not tag `latest`. Deploy by immutable image digest; rollback by restoring the last approved configuration/model/container tuple. Mount the runtime OPC UA configuration and certificates read-only, and provide writable log/audit paths explicitly. The service has no model backend and must remain not-ready until a separately approved production adapter is injected.

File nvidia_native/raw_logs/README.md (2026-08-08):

# Native NVIDIA raw-log status

> FICTIONAL ENGINEERING PROJECT - NOT FOR CONSTRUCTION.

> CONCEPTUAL SAFETY ARCHITECTURE - REQUIRES PROJECT-SPECIFIC RISK ASSESSMENT, DESIGN, VERIFICATION AND VALIDATION BY A QUALIFIED MACHINERY-SAFETY ENGINEER. NO PERFORMANCE LEVEL, SIL, CATEGORY, CE/UKCA CONFORMITY OR REGULATORY COMPLIANCE IS CLAIMED.

No training, evaluation, ONNX, TensorRT, DeepStream, container-build or target-runtime log was produced. Future raw logs must be stored unchanged, hashed and referenced from the model/container release record; sanitized summaries must never replace raw evidence.

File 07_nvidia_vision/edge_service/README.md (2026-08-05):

# NVIDIA edge-service source boundary

> FICTIONAL ENGINEERING PROJECT — NOT FOR CONSTRUCTION

> CONCEPTUAL SAFETY ARCHITECTURE — REQUIRES PROJECT-SPECIFIC RISK ASSESSMENT, DESIGN, VERIFICATION AND VALIDATION BY A QUALIFIED MACHINERY-SAFETY ENGINEER. NO PERFORMANCE LEVEL, SIL, CATEGORY, CE CONFORMITY OR REGULATORY COMPLIANCE IS CLAIMED.

`protocol.py` is the edge-service protocol oracle. It defines the controlled target-fill bounds (0.1 through 1.0), request/result rules, exact model identity checks and a hexadecimal SHA-256 requirement. `service.py` adds fail-closed 1000 ms PLC-heartbeat supervision, compares every result to the backend's controlled identity, and can adopt a validated unacknowledged server-side publication after a cold edge-process restart without re-running inference.

Revision F retains the genuine `asyncua` 2.0.1 client and expands the additive namespace to 47 nodes. It requires Basic256Sha256/SignAndEncrypt, a named X.509 user, a trusted server certificate/CA and CRL store, validates every NodeId, data type and least-privilege access right, reads coherent counter/session/configuration snapshots, writes the result payload before `RESULT_VALID`, preserves that payload until exact acknowledgement, reconnects with bounded exponential backoff and fails closed on stale, malformed or contradictory data. `observability.py` provides JSON-line logs, fixed-cardinality metrics and loopback-only health/readiness endpoints. Configuration and PKI material are described by `opcua_runtime_config.json`; secrets and certificates remain external to the repository.

At process startup or reconnect the adapter must keep `READY` low. After observing `VISION_ENABLE=0`, it must take one coherent PLC snapshot of `VISION_SESSION_EPOCH`, `INSPECTION_ID`, `RESULT_ACK_ID` and `PLC_HEARTBEAT`, pass those four values to `VisionService.reset`, and only then assert `READY`. Those PLC-owned counter baselines prevent a cold edge process from replaying an already issued identifier in an unchanged session. Session changes use the same disabled synchronization; changing a session while enabled is rejected.

The secure integration suite creates an ephemeral CA, server and named client certificates and runs a real asyncua server/client session. It verifies the secure endpoint, non-anonymous identity, 47-node contract, payload-before-valid order, exact acknowledgement, restart restoration, trust rejection, immutable-publication tamper detection, missed-request fail-closed behavior and bounded late-result suppression. This is local software evidence, not a connection to the Siemens CPU and not site PKI validation.

## Offline buffering policy

There is no offline request, image or result queue and no later replay for product disposition. The only retained transaction is one immutable result already published in the OPC UA server and awaiting its exact same-session acknowledgement. A disconnect, ambiguous read/write completion or loss of a coherent PLC snapshot forces READY low and the PLC remains in HOLD. Recovery requires disabled-state synchronization and coherent reconciliation of the session, inspection, acknowledgement and heartbeat counters before READY may return. An image, request or result that was not coherently completed online is never silently reused for another bottle.

## Software rollback boundary

The adapter package, locked requirements, runtime configuration and systemd unit are versioned and rolled back together through the controlled procedure in `opcua_adapter_runbook.md`. Rollback begins with the service stopped and production disabled; the previously reviewed package is restored, hashes and PKI permissions are checked, the complete 47-node map is revalidated, and the service cold-starts disabled before negative tests are repeated. Model rollback is separate and remains blocked until a genuine approved model lifecycle exists.

`vision_runtime.py` now supplies a manifest-driven exactly-once recorded-image source, bounded preprocessing boundary, explicit test-only mock, fail-closed ONNX adapter structure and result post-processing. A development/synthetic backend is prohibited from asserting service READY. `dataset_tool.py` validates hashes/schema/review/split leakage, assigns deterministic production-lot/session splits and calculates supplied binary confusion/false-accept/false-reject metrics. No camera driver, production inference backend, dataset, model, ONNX file, TensorRT engine or DeepStream execution is delivered. `main.py` therefore starts with no backend and intentionally holds `VISION_READY` low.

See `opcua_adapter_runbook.md` for installation, PKI, test and deployment steps. The hardened systemd unit is a deployment baseline only and requires target Linux/Jetson, site account, firewall and cybersecurity approval.

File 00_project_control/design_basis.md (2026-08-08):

# Design basis - Revision F

> FICTIONAL ENGINEERING PROJECT - NOT FOR CONSTRUCTION.

> CONCEPTUAL SAFETY ARCHITECTURE - REQUIRES PROJECT-SPECIFIC RISK ASSESSMENT, DESIGN, VERIFICATION AND VALIDATION BY A QUALIFIED MACHINERY-SAFETY ENGINEER. NO PERFORMANCE LEVEL, SIL, CATEGORY, CE/UKCA CONFORMITY OR REGULATORY COMPLIANCE IS CLAIMED.

The canonical owner is `00_project_control/canonical_model.json`. Revision F overlays the frozen Revision-E baseline without weakening Git-object byte authority or native evidence boundaries. The 47-node OPC UA contract preserves the original 27 nodes and immutable session/inspection/ACK lifecycle. Result age is calculated by the PLC from monotonic transaction time; edge UTC timestamps are diagnostic.

The edge service is a non-safety quality subsystem. THE NVIDIA VISION SUBSYSTEM IS NON-SAFETY-RELATED AND MUST NOT BE USED AS THE SOLE MEANS OF PERSONNEL PROTECTION, SAFE STOP, GUARD MONITORING OR HAZARDOUS-MOTION CONTROL. Flow and level instrumentation remains the primary deterministic fill measurement. Representative data, target hardware and native/physical evidence remain controlled external gates.

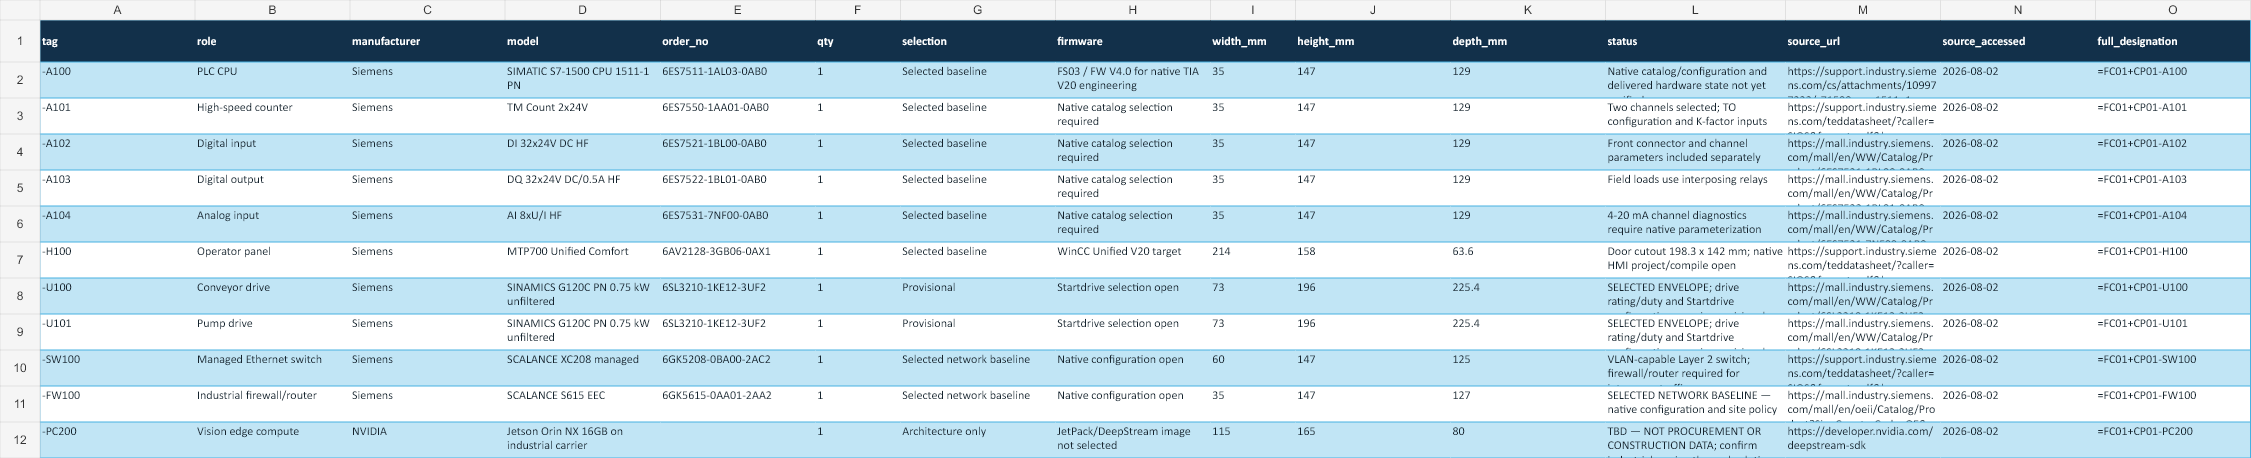
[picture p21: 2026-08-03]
14_qa/workbook_renders/siemens-hardware.png

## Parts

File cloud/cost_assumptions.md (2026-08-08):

# Cloud cost assumptions

> FICTIONAL ENGINEERING PROJECT - NOT FOR CONSTRUCTION.

> CONCEPTUAL SAFETY ARCHITECTURE - REQUIRES PROJECT-SPECIFIC RISK ASSESSMENT, DESIGN, VERIFICATION AND VALIDATION BY A QUALIFIED MACHINERY-SAFETY ENGINEER. NO PERFORMANCE LEVEL, SIL, CATEGORY, CE/UKCA CONFORMITY OR REGULATORY COMPLIANCE IS CLAIMED.

No cloud resource was created and actual cost is **EUR/USD 0.00 from this Revision-G execution**.

The estimate is intentionally formula-driven because project region, quota, current price, Windows licence treatment, discounts and run hours are not approved:

`monthly estimate = Windows VM hourly rate * approved hours + GPU VM hourly rate * active training hours + persistent-disk GB-month + snapshot GB-month + object-storage GB-month + network/NAT/logging charges`.

Before plan approval, the owner must record a dated Google Cloud Pricing Calculator export for the selected region and a maximum monthly budget. Budget alerts are notifications and do not automatically cap ordinary Compute Engine spend. Stopping a VM stops vCPU/GPU runtime charges but does not remove persistent disk, snapshot, IP/NAT, Data Access logging, monitoring or storage charges. The Terraform defaults keep both VMs disabled and configure weekday shutdown schedules if enabled. Audit-log volume and retention must be priced before apply.

Official sources: https://cloud.google.com/products/calculator, https://cloud.google.com/billing/docs/how-to/budgets, https://cloud.google.com/compute/docs/instances/schedule-instance-start-stop.

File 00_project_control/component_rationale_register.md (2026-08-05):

# Component rationale register - Revision F

> FICTIONAL ENGINEERING PROJECT — NOT FOR CONSTRUCTION

> CONCEPTUAL SAFETY ARCHITECTURE — REQUIRES PROJECT-SPECIFIC RISK ASSESSMENT, DESIGN, VERIFICATION AND VALIDATION BY A QUALIFIED MACHINERY-SAFETY ENGINEER. NO PERFORMANCE LEVEL, SIL, CATEGORY, CE CONFORMITY OR REGULATORY COMPLIANCE IS CLAIMED.

Generated from the controlled canonical model. Software-agent consistency review is not qualified-human approval.

| Category | Key | Purpose | Failure detected or controlled | Basis | Open verification | Owner |
|---|---|---|---|---|---|---|
| Component | -A100 | SIMATIC S7-1500 CPU 1511-1 PN | Loss or failure affects the scheduled machine function; mapped I/O/alarm response applies where instrumented | Selected baseline | Native catalog/configuration and delivered hardware state not yet verified | Electrical/controls owner |
| Component | -A101 | TM Count 2x24V | Loss or failure affects the scheduled machine function; mapped I/O/alarm response applies where instrumented | Selected baseline | Two channels selected; TO configuration and K-factor inputs open | Electrical/controls owner |
| Component | -A102 | DI 32x24V DC HF | Loss or failure affects the scheduled machine function; mapped I/O/alarm response applies where instrumented | Selected baseline | Front connector and channel parameters included separately | Electrical/controls owner |
| Component | -A103 | DQ 32x24V DC/0.5A HF | Loss or failure affects the scheduled machine function; mapped I/O/alarm response applies where instrumented | Selected baseline | Field loads use interposing relays | Electrical/controls owner |
| Component | -A104 | AI 8xU/I HF | Loss or failure affects the scheduled machine function; mapped I/O/alarm response applies where instrumented | Selected baseline | 4-20 mA channel diagnostics require native parameterization | Electrical/controls owner |
| Component | -B100 | Pneumatic pressure switch | Loss or failure affects the scheduled machine function; mapped I/O/alarm response applies where instrumented | TBD | Automatically added from canonical I/O; exact device selection open | Electrical/controls owner |
| Component | -B101 | Product supply permissive | Loss or failure affects the scheduled machine function; mapped I/O/alarm response applies where instrumented | TBD | Automatically added from canonical I/O; exact device selection open | Electrical/controls owner |
| Component | -B110 | Bottle 1 position sensor | Loss or failure affects the scheduled machine function; mapped I/O/alarm response applies where instrumented | TBD | Automatically added from canonical I/O; exact device selection open | Electrical/controls owner |
| Component | -B111 | Bottle 2 position sensor | Loss or failure affects the scheduled machine function; mapped I/O/alarm response applies where instrumented | TBD | Automatically added from canonical I/O; exact device selection open | Electrical/controls owner |
| Component | -B120 | Gate open feedback | Loss or failure affects the scheduled machine function; mapped I/O/alarm response applies where instrumented | TBD | Automatically added from canonical I/O; exact device selection open | Electrical/controls owner |
| Component | -B121 | Gate closed feedback | Loss or failure affects the scheduled machine function; mapped I/O/alarm response applies where instrumented | TBD | Automatically added from canonical I/O; exact device selection open | Electrical/controls owner |
| Component | -B122 | Clamp released feedback | Loss or failure affects the scheduled machine function; mapped I/O/alarm response applies where instrumented | TBD | Automatically added from canonical I/O; exact device selection open | Electrical/controls owner |
| Component | -B123 | Clamp engaged feedback | Loss or failure affects the scheduled machine function; mapped I/O/alarm response applies where instrumented | TBD | Automatically added from canonical I/O; exact device selection open | Electrical/controls owner |
| Component | -B130 | Valve 1 closed proof | Loss or failure affects the scheduled machine function; mapped I/O/alarm response applies where instrumented | TBD | Automatically added from canonical I/O; exact device selection open | Electrical/controls owner |
| Component | -B131 | Valve 2 closed proof | Loss or failure affects the scheduled machine function; mapped I/O/alarm response applies where instrumented | TBD | Automatically added from canonical I/O; exact device selection open | Electrical/controls owner |
| Component | -CAM200 | Industrial camera | Loss or failure affects the scheduled machine function; mapped I/O/alarm response applies where instrumented | TBD | Vision physical basis and target interface open | Electrical/controls owner |
| Component | -CB200 | Industrial Jetson carrier | Loss or failure affects the scheduled machine function; mapped I/O/alarm response applies where instrumented | TBD | Power, lifecycle, thermal and EMC selection open | Electrical/controls owner |
| Component | -CONS100 | Markers, ferrules, lugs, ties and installation consumables | Loss or failure affects the scheduled machine function; mapped I/O/alarm response applies where instrumented | TBD | Quantity after detailed design | Electrical/controls owner |
| Component | -D202..-D213 | Coil suppression modules | Loss or failure affects the scheduled machine function; mapped I/O/alarm response applies where instrumented | TBD | One device per active relay; match relay coil technology | Electrical/controls owner |
| Component | -DR100 | 35 mm DIN rail set | Loss or failure affects the scheduled machine function; mapped I/O/alarm response applies where instrumented | TBD | Final layout open | Electrical/controls owner |
| Component | -ENC100 | IP-rated enclosure with mounting plate | Loss or failure affects the scheduled machine function; mapped I/O/alarm response applies where instrumented | TBD | Environment, IP rating and thermal calculation open | Electrical/controls owner |
| Component | -FAN100 | Filter fan / cooling solution | Loss or failure affects the scheduled machine function; mapped I/O/alarm response applies where instrumented | TBD | Thermal model and ambient inputs open | Electrical/controls owner |
| Component | -FC100 | Front connector for DI module | Loss or failure affects the scheduled machine function; mapped I/O/alarm response applies where instrumented | TBD | Exact accessory to be confirmed in TIA Selection Tool | Electrical/controls owner |
| Component | -FC101 | Front connector for DQ module | Loss or failure affects the scheduled machine function; mapped I/O/alarm response applies where instrumented | TBD | Exact accessory to be confirmed in TIA Selection Tool | Electrical/controls owner |
| Component | -FC102 | Front connector for AI module | Loss or failure affects the scheduled machine function; mapped I/O/alarm response applies where instrumented | TBD | Exact accessory to be confirmed in TIA Selection Tool | Electrical/controls owner |
| Component | -FC103 | Front connector for TM Count module | Loss or failure affects the scheduled machine function; mapped I/O/alarm response applies where instrumented | TBD | Exact accessory to be confirmed in TIA Selection Tool | Electrical/controls owner |
| Component | -FT100 | Pulse plus 4-20 mA flowmeter channel 1 | Loss or failure affects the scheduled machine function; mapped I/O/alarm response applies where instrumented | TBD | K-factor, max pulse rate and analog diagnostics required | Electrical/controls owner |
| Component | -FT101 | Pulse plus 4-20 mA flowmeter channel 2 | Loss or failure affects the scheduled machine function; mapped I/O/alarm response applies where instrumented | TBD | K-factor, max pulse rate and analog diagnostics required | Electrical/controls owner |
| Component | -FW100 | SCALANCE S615 EEC | Loss or failure affects the scheduled machine function; mapped I/O/alarm response applies where instrumented | Selected network baseline | Exact width and site policy remain procurement/native gates | Electrical/controls owner |
| Component | -GL100 | Cable glands and EMC glands | Loss or failure affects the scheduled machine function; mapped I/O/alarm response applies where instrumented | TBD | Cable OD and IP rating open | Electrical/controls owner |
| Component | -H100 | MTP700 Unified Comfort | Loss or failure affects the scheduled machine function; mapped I/O/alarm response applies where instrumented | Selected baseline | Door cutout 198.3 x 142 mm; native HMI project/compile open | Electrical/controls owner |
| Component | -H101 | Three-color stack light with sounder | Loss or failure affects the scheduled machine function; mapped I/O/alarm response applies where instrumented | TBD | Lens, sound level and mounting open | Electrical/controls owner |
| Component | -IF140 | Capper interface terminals/relays | Loss or failure affects the scheduled machine function; mapped I/O/alarm response applies where instrumented | TBD | Interface specification missing | Electrical/controls owner |
| Component | -K100 | Main control enable contactor / external safety interface with dry monitoring contact | Loss or failure affects the scheduled machine function; mapped I/O/alarm response applies where instrumented | TBD | Qualified safety design external | Electrical/controls owner |
| Component | -K202..-K213 | Interposing relays with bases and status indication | Loss or failure affects the scheduled machine function; mapped I/O/alarm response applies where instrumented | TBD | Twelve active output relays; coil/contact/load ratings and approved supplier missing | Electrical/controls owner |
| Component | -LENS200 | C-mount lens | Loss or failure affects the scheduled machine function; mapped I/O/alarm response applies where instrumented | TBD | Sensor, FOV, working distance and DoF open | Electrical/controls owner |
| Component | -LT200 | Machine-vision backlight/front-light assembly | Loss or failure affects the scheduled machine function; mapped I/O/alarm response applies where instrumented | TBD | Optical trials and exposure limits open | Electrical/controls owner |
| Component | -M100 | Conveyor motor | Loss or failure affects the scheduled machine function; mapped I/O/alarm response applies where instrumented | TBD | Nameplate, duty, cable and mechanical data required | Electrical/controls owner |
| Component | -M101 | Pump motor | Loss or failure affects the scheduled machine function; mapped I/O/alarm response applies where instrumented | TBD | Pump curve, nameplate, dead-head and cable data required | Electrical/controls owner |
| Component | -MC100 | SIMATIC memory card; capacity to be selected after compiled project sizing | Loss or failure affects the scheduled machine function; mapped I/O/alarm response applies where instrumented | TBD | Native compiled project size unavailable | Electrical/controls owner |
| Component | -PC200 | Jetson Orin NX 16GB on industrial carrier | Loss or failure affects the scheduled machine function; mapped I/O/alarm response applies where instrumented | Architecture only | Carrier, thermals, power, EMC and lifecycle are open | Electrical/controls owner |
| Component | -PE100 | Copper protective-earth bar and bonding hardware | Loss or failure affects the scheduled machine function; mapped I/O/alarm response applies where instrumented | TBD | PE sizing requires supply/earthing inputs | Electrical/controls owner |
| Component | -PS100 | 24 VDC 20 A power supply | Loss or failure affects the scheduled machine function; mapped I/O/alarm response applies where instrumented | Provisional | Demand estimate includes margin; inrush and derating open | Electrical/controls owner |
| Component | -QF100 | Main protective device | Loss or failure affects the scheduled machine function; mapped I/O/alarm response applies where instrumented | TBD | Fault level, load and selectivity study missing | Electrical/controls owner |
| Component | -QF110 | 24 VDC electronic branch protection | Loss or failure affects the scheduled machine function; mapped I/O/alarm response applies where instrumented | TBD | Branch currents and discrimination require device data | Electrical/controls owner |
| Component | -QS100 | Main door-coupled isolator | Loss or failure affects the scheduled machine function; mapped I/O/alarm response applies where instrumented | TBD | Supply, fault current and regulatory basis missing | Electrical/controls owner |
| Component | -RA100 | S7-1500 mounting rail and fixing hardware | Loss or failure affects the scheduled machine function; mapped I/O/alarm response applies where instrumented | TBD | Rail length depends on final cabinet layout | Electrical/controls owner |
| Component | -S100 | Local reset pushbutton | Loss or failure affects the scheduled machine function; mapped I/O/alarm response applies where instrumented | TBD | Operator-station family and IP rating open | Electrical/controls owner |
| Component | -S101 | Local controlled-stop pushbutton | Loss or failure affects the scheduled machine function; mapped I/O/alarm response applies where instrumented | TBD | Not a safety stop; operator-station family open | Electrical/controls owner |
| Component | -S102 | Guard-status dry-contact monitoring interface | Loss or failure affects the scheduled machine function; mapped I/O/alarm response applies where instrumented | TBD | Monitoring only; qualified guard-interlocking design remains external | Electrical/controls owner |
| Component | -SC100 | Shield-clamp rail and spring clamps | Loss or failure affects the scheduled machine function; mapped I/O/alarm response applies where instrumented | Provisional quantity | Cable OD and final shield count open | Electrical/controls owner |
| Component | -SW100 | SCALANCE XC208 managed | Loss or failure affects the scheduled machine function; mapped I/O/alarm response applies where instrumented | Selected network baseline | VLAN-capable Layer 2 switch; firewall/router required for inter-zone traffic | Electrical/controls owner |
| Component | -U100 | SINAMICS G120C PN 0.75 kW unfiltered | Loss or failure affects the scheduled machine function; mapped I/O/alarm response applies where instrumented | Provisional | Rating, envelope and clearances blocked by motor/mechanics and native Startdrive | Electrical/controls owner |
| Component | -U101 | SINAMICS G120C PN 0.75 kW unfiltered | Loss or failure affects the scheduled machine function; mapped I/O/alarm response applies where instrumented | Provisional | Rating, envelope and clearances blocked by pump curve and motor data | Electrical/controls owner |
| Component | -W900 | Industrial Ethernet patch cables/connectors | Loss or failure affects the scheduled machine function; mapped I/O/alarm response applies where instrumented | Provisional quantity | Lengths and routing open | Electrical/controls owner |
| Component | -W901 | Shielded VFD motor cables and EMC termination kits | Loss or failure affects the scheduled machine function; mapped I/O/alarm response applies where instrumented | TBD | Motor cable lengths and drive EMC design open | Electrical/controls owner |
| Component | -WD100 | Slotted wiring duct set | Loss or failure affects the scheduled machine function; mapped I/O/alarm response applies where instrumented | TBD | Duct fill pending final conductors | Electrical/controls owner |
| Component | -X100..-X199 | DIN-rail terminal blocks, disconnect/test where required | Loss or failure affects the scheduled machine function; mapped I/O/alarm response applies where instrumented | Provisional quantity | Final QET continuity and terminal-family selection open | Electrical/controls owner |
| Component | -YV100 | Gate valve/cylinder solenoid | Loss or failure affects the scheduled machine function; mapped I/O/alarm response applies where instrumented | TBD | Coil current, response and fail state required | Electrical/controls owner |
| Component | -YV101 | Clamp valve/cylinder solenoid | Loss or failure affects the scheduled machine function; mapped I/O/alarm response applies where instrumented | TBD | Coil current, response and fail state required | Electrical/controls owner |
| Component | -YV102 | Fill valve channel 1, fail closed | Loss or failure affects the scheduled machine function; mapped I/O/alarm response applies where instrumented | TBD | Wetted materials, Kv, coil and closing time required | Electrical/controls owner |
| Component | -YV103 | Fill valve channel 2, fail closed | Loss or failure affects the scheduled machine function; mapped I/O/alarm response applies where instrumented | TBD | Wetted materials, Kv, coil and closing time required | Electrical/controls owner |
| PLC channel | AIR_PRESSURE_OK | Pneumatic pressure switch | Detects or controls the named function; spares remain de-energized | DI I0.2 on -A102 2 | Native hardware assignment, diagnostics and checkout | Controls owner |
| PLC channel | AI_SPARE_01 | Allocated spare analog input | Detects or controls the named function; spares remain de-energized | AI IW68 on -A104 2 | Native hardware assignment, diagnostics and checkout | Controls owner |
| PLC channel | AI_SPARE_02 | Allocated spare analog input | Detects or controls the named function; spares remain de-energized | AI IW70 on -A104 3 | Native hardware assignment, diagnostics and checkout | Controls owner |
| PLC channel | AI_SPARE_03 | Allocated spare analog input | Detects or controls the named function; spares remain de-energized | AI IW72 on -A104 4 | Native hardware assignment, diagnostics and checkout | Controls owner |
| PLC channel | AI_SPARE_04 | Allocated spare analog input | Detects or controls the named function; spares remain de-energized | AI IW74 on -A104 5 | Native hardware assignment, diagnostics and checkout | Controls owner |
| PLC channel | AI_SPARE_05 | Allocated spare analog input | Detects or controls the named function; spares remain de-energized | AI IW76 on -A104 6 | Native hardware assignment, diagnostics and checkout | Controls owner |
| PLC channel | AI_SPARE_06 | Allocated spare analog input | Detects or controls the named function; spares remain de-energized | AI IW78 on -A104 7 | Native hardware assignment, diagnostics and checkout | Controls owner |
| PLC channel | AUDIBLE_ALARM | Sounder relay | Detects or controls the named function; spares remain de-energized | DO Q1.4 on -A103 12 | Native hardware assignment, diagnostics and checkout | Controls owner |
| PLC channel | BOTTLE_AT_NEST_1 | Bottle 1 position sensor | Detects or controls the named function; spares remain de-energized | DI I1.2 on -A102 10 | Native hardware assignment, diagnostics and checkout | Controls owner |
| PLC channel | BOTTLE_AT_NEST_2 | Bottle 2 position sensor | Detects or controls the named function; spares remain de-energized | DI I1.3 on -A102 11 | Native hardware assignment, diagnostics and checkout | Controls owner |
| PLC channel | CAMERA_LIGHT_ENABLE | Vision lighting relay | Detects or controls the named function; spares remain de-energized | DO Q1.5 on -A103 13 | Native hardware assignment, diagnostics and checkout | Controls owner |
| PLC channel | CAPPER_BUSY | Capping station busy | Detects or controls the named function; spares remain de-energized | DI I2.3 on -A102 19 | Native hardware assignment, diagnostics and checkout | Controls owner |
| PLC channel | CAPPER_COMPLETE | Capping complete acknowledgement | Detects or controls the named function; spares remain de-energized | DI I2.4 on -A102 20 | Native hardware assignment, diagnostics and checkout | Controls owner |
| PLC channel | CAPPER_FAULT | Capping fault | Detects or controls the named function; spares remain de-energized | DI I2.5 on -A102 21 | Native hardware assignment, diagnostics and checkout | Controls owner |
| PLC channel | CAPPER_READY | Capping station ready | Detects or controls the named function; spares remain de-energized | DI I2.2 on -A102 18 | Native hardware assignment, diagnostics and checkout | Controls owner |
| PLC channel | CAPPER_REQUEST | Capping request relay | Detects or controls the named function; spares remain de-energized | DO Q1.0 on -A103 8 | Native hardware assignment, diagnostics and checkout | Controls owner |
| PLC channel | CLAMP_ENGAGED_FB | Clamp engaged feedback | Detects or controls the named function; spares remain de-energized | DI I1.7 on -A102 15 | Native hardware assignment, diagnostics and checkout | Controls owner |
| PLC channel | CLAMP_ENGAGE_CMD | Clamp engage relay | Detects or controls the named function; spares remain de-energized | DO Q0.6 on -A103 6 | Native hardware assignment, diagnostics and checkout | Controls owner |
| PLC channel | CLAMP_RELEASED_FB | Clamp released feedback | Detects or controls the named function; spares remain de-energized | DI I1.6 on -A102 14 | Native hardware assignment, diagnostics and checkout | Controls owner |
| PLC channel | CLAMP_RELEASE_CMD | Clamp release relay | Detects or controls the named function; spares remain de-energized | DO Q0.7 on -A103 7 | Native hardware assignment, diagnostics and checkout | Controls owner |
| PLC channel | DI_SPARE_01 | Allocated spare input | Detects or controls the named function; spares remain de-energized | DI I3.0 on -A102 24 | Native hardware assignment, diagnostics and checkout | Controls owner |
| PLC channel | DI_SPARE_02 | Allocated spare input | Detects or controls the named function; spares remain de-energized | DI I3.1 on -A102 25 | Native hardware assignment, diagnostics and checkout | Controls owner |
| PLC channel | DI_SPARE_03 | Allocated spare input | Detects or controls the named function; spares remain de-energized | DI I3.2 on -A102 26 | Native hardware assignment, diagnostics and checkout | Controls owner |
| PLC channel | DI_SPARE_04 | Allocated spare input | Detects or controls the named function; spares remain de-energized | DI I3.3 on -A102 27 | Native hardware assignment, diagnostics and checkout | Controls owner |
| PLC channel | DI_SPARE_05 | Allocated spare input | Detects or controls the named function; spares remain de-energized | DI I3.4 on -A102 28 | Native hardware assignment, diagnostics and checkout | Controls owner |
| PLC channel | DI_SPARE_06 | Allocated spare input | Detects or controls the named function; spares remain de-energized | DI I3.5 on -A102 29 | Native hardware assignment, diagnostics and checkout | Controls owner |
| PLC channel | DI_SPARE_07 | Allocated spare input | Detects or controls the named function; spares remain de-energized | DI I3.6 on -A102 30 | Native hardware assignment, diagnostics and checkout | Controls owner |
| PLC channel | DI_SPARE_08 | Allocated spare input | Detects or controls the named function; spares remain de-energized | DI I3.7 on -A102 31 | Native hardware assignment, diagnostics and checkout | Controls owner |
| PLC channel | DI_SPARE_DRIVE_REMOVED_01 | Spare channel; hardwired drive run/status removed because Standard Telegram 1 PROFINET is primary | Detects or controls the named function; spares remain de-energized | DI I0.4 on -A102 4 | Native hardware assignment, diagnostics and checkout | Controls owner |
| PLC channel | DI_SPARE_DRIVE_REMOVED_02 | Spare channel; hardwired drive run/status removed because Standard Telegram 1 PROFINET is primary | Detects or controls the named function; spares remain de-energized | DI I0.5 on -A102 5 | Native hardware assignment, diagnostics and checkout | Controls owner |
| PLC channel | DI_SPARE_DRIVE_REMOVED_03 | Spare channel; hardwired drive run/status removed because Standard Telegram 1 PROFINET is primary | Detects or controls the named function; spares remain de-energized | DI I0.6 on -A102 6 | Native hardware assignment, diagnostics and checkout | Controls owner |
| PLC channel | DI_SPARE_DRIVE_REMOVED_04 | Spare channel; hardwired drive run/status removed because Standard Telegram 1 PROFINET is primary | Detects or controls the named function; spares remain de-energized | DI I0.7 on -A102 7 | Native hardware assignment, diagnostics and checkout | Controls owner |
| PLC channel | DI_SPARE_DRIVE_REMOVED_05 | Spare channel; hardwired drive run/status removed because Standard Telegram 1 PROFINET is primary | Detects or controls the named function; spares remain de-energized | DI I1.0 on -A102 8 | Native hardware assignment, diagnostics and checkout | Controls owner |
| PLC channel | DI_SPARE_DRIVE_REMOVED_06 | Spare channel; hardwired drive run/status removed because Standard Telegram 1 PROFINET is primary | Detects or controls the named function; spares remain de-energized | DI I1.1 on -A102 9 | Native hardware assignment, diagnostics and checkout | Controls owner |
| PLC channel | DO_SPARE_01 | Allocated spare output | Detects or controls the named function; spares remain de-energized | DO Q1.6 on -A103 14 | Native hardware assignment, diagnostics and checkout | Controls owner |
| PLC channel | DO_SPARE_02 | Allocated spare output | Detects or controls the named function; spares remain de-energized | DO Q1.7 on -A103 15 | Native hardware assignment, diagnostics and checkout | Controls owner |
| PLC channel | DO_SPARE_03 | Allocated spare output | Detects or controls the named function; spares remain de-energized | DO Q2.0 on -A103 16 | Native hardware assignment, diagnostics and checkout | Controls owner |
| PLC channel | DO_SPARE_04 | Allocated spare output | Detects or controls the named function; spares remain de-energized | DO Q2.1 on -A103 17 | Native hardware assignment, diagnostics and checkout | Controls owner |
| PLC channel | DO_SPARE_05 | Allocated spare output | Detects or controls the named function; spares remain de-energized | DO Q2.2 on -A103 18 | Native hardware assignment, diagnostics and checkout | Controls owner |
| PLC channel | DO_SPARE_06 | Allocated spare output | Detects or controls the named function; spares remain de-energized | DO Q2.3 on -A103 19 | Native hardware assignment, diagnostics and checkout | Controls owner |
| PLC channel | DO_SPARE_07 | Allocated spare output | Detects or controls the named function; spares remain de-energized | DO Q2.4 on -A103 20 | Native hardware assignment, diagnostics and checkout | Controls owner |
| PLC channel | DO_SPARE_08 | Allocated spare output | Detects or controls the named function; spares remain de-energized | DO Q2.5 on -A103 21 | Native hardware assignment, diagnostics and checkout | Controls owner |
| PLC channel | DO_SPARE_09 | Allocated spare output | Detects or controls the named function; spares remain de-energized | DO Q2.6 on -A103 22 | Native hardware assignment, diagnostics and checkout | Controls owner |
| PLC channel | DO_SPARE_10 | Allocated spare output | Detects or controls the named function; spares remain de-energized | DO Q2.7 on -A103 23 | Native hardware assignment, diagnostics and checkout | Controls owner |
| PLC channel | DO_SPARE_11 | Allocated spare output | Detects or controls the named function; spares remain de-energized | DO Q3.0 on -A103 24 | Native hardware assignment, diagnostics and checkout | Controls owner |
| PLC channel | DO_SPARE_12 | Allocated spare output | Detects or controls the named function; spares remain de-energized | DO Q3.1 on -A103 25 | Native hardware assignment, diagnostics and checkout | Controls owner |
| PLC channel | DO_SPARE_13 | Allocated spare output | Detects or controls the named function; spares remain de-energized | DO Q3.2 on -A103 26 | Native hardware assignment, diagnostics and checkout | Controls owner |
| PLC channel | DO_SPARE_14 | Allocated spare output | Detects or controls the named function; spares remain de-energized | DO Q3.3 on -A103 27 | Native hardware assignment, diagnostics and checkout | Controls owner |
| PLC channel | DO_SPARE_15 | Allocated spare output | Detects or controls the named function; spares remain de-energized | DO Q3.4 on -A103 28 | Native hardware assignment, diagnostics and checkout | Controls owner |
| PLC channel | DO_SPARE_16 | Allocated spare output | Detects or controls the named function; spares remain de-energized | DO Q3.5 on -A103 29 | Native hardware assignment, diagnostics and checkout | Controls owner |
| PLC channel | DO_SPARE_17 | Allocated spare output | Detects or controls the named function; spares remain de-energized | DO Q3.6 on -A103 30 | Native hardware assignment, diagnostics and checkout | Controls owner |
| PLC channel | DO_SPARE_18 | Allocated spare output | Detects or controls the named function; spares remain de-energized | DO Q3.7 on -A103 31 | Native hardware assignment, diagnostics and checkout | Controls owner |
| PLC channel | DO_SPARE_DRIVE_REMOVED_01 | Spare channel; hardwired drive run/status removed because Standard Telegram 1 PROFINET is primary | Detects or controls the named function; spares remain de-energized | DO Q0.0 on -A103 0 | Native hardware assignment, diagnostics and checkout | Controls owner |
| PLC channel | DO_SPARE_DRIVE_REMOVED_02 | Spare channel; hardwired drive run/status removed because Standard Telegram 1 PROFINET is primary | Detects or controls the named function; spares remain de-energized | DO Q0.1 on -A103 1 | Native hardware assignment, diagnostics and checkout | Controls owner |
| PLC channel | FILL_VALVE_1_CLOSED_FB | Valve 1 closed proof | Detects or controls the named function; spares remain de-energized | DI I2.0 on -A102 16 | Native hardware assignment, diagnostics and checkout | Controls owner |
| PLC channel | FILL_VALVE_1_OPEN_CMD | Valve 1 interposing relay | Detects or controls the named function; spares remain de-energized | DO Q0.2 on -A103 2 | Native hardware assignment, diagnostics and checkout | Controls owner |
| PLC channel | FILL_VALVE_2_CLOSED_FB | Valve 2 closed proof | Detects or controls the named function; spares remain de-energized | DI I2.1 on -A102 17 | Native hardware assignment, diagnostics and checkout | Controls owner |
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

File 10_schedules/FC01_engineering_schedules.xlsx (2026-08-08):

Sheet: Siemens Hardware
tag | role | manufacturer | model | order_no | qty | selection | firmware | width_mm | height_mm | depth_mm | status | source_url | source_accessed | full_designation
-A100 | PLC CPU | Siemens | SIMATIC S7-1500 CPU 1511-1 PN | 6ES7511-1AL03-0AB0 | 1 | Selected baseline | FS03 / FW V4.0 for native TIA V20 engineering | 35 | 147 | 129 | Native catalog/configuration and delivered hardware state not yet verified | https://support.industry.siemens.com/cs/attachments/109977233/s71500_cpu1511_1_pn_dtc_manual_en-US_en-US.pdf | 2026-08-02 | =FC01+CP01-A100
-A101 | High-speed counter | Siemens | TM Count 2x24V | 6ES7550-1AA01-0AB0 | 1 | Selected baseline | Native catalog selection required | 35 | 147 | 129 | Two channels selected; TO configuration and K-factor inputs open | https://support.industry.siemens.com/teddatasheet/?caller=SIOS&format=pdf&language=en&mlfbs=6ES7550-1AA01-0AB0 | 2026-08-02 | =FC01+CP01-A101
-A102 | Digital input | Siemens | DI 32x24V DC HF | 6ES7521-1BL00-0AB0 | 1 | Selected baseline | Native catalog selection required | 35 | 147 | 129 | Front connector and channel parameters included separately | https://mall.industry.siemens.com/mall/en/WW/Catalog/Product/6ES7521-1BL00-0AB0 | 2026-08-02 | =FC01+CP01-A102
-A103 | Digital output | Siemens | DQ 32x24V DC/0.5A HF | 6ES7522-1BL01-0AB0 | 1 | Selected baseline | Native catalog selection required | 35 | 147 | 129 | Field loads use interposing relays | https://mall.industry.siemens.com/mall/en/WW/Catalog/Product/6ES7522-1BL01-0AB0 | 2026-08-02 | =FC01+CP01-A103
-A104 | Analog input | Siemens | AI 8xU/I HF | 6ES7531-7NF00-0AB0 | 1 | Selected baseline | Native catalog selection required | 35 | 147 | 129 | 4-20 mA channel diagnostics require native parameterization | https://mall.industry.siemens.com/mall/en/WW/Catalog/Product/6ES7531-7NF00-0AB0 | 2026-08-02 | =FC01+CP01-A104
-H100 | Operator panel | Siemens | MTP700 Unified Comfort | 6AV2128-3GB06-0AX1 | 1 | Selected baseline | WinCC Unified V20 target | 214 | 158 | 63.6 | Door cutout 198.3 x 142 mm; native HMI project/compile open | https://support.industry.siemens.com/teddatasheet/?caller=SIOS&format=pdf&language=en&mlfbs=6AV2128-3GB06-0AX1 | 2026-08-02 | =FC01+CP01-H100
-U100 | Conveyor drive | Siemens | SINAMICS G120C PN 0.75 kW unfiltered | 6SL3210-1KE12-3UF2 | 1 | Provisional | Startdrive selection open | 73 | 196 | 225.4 | SELECTED ENVELOPE; drive rating/duty and Startdrive configuration remain provisional | https://mall.industry.siemens.com/mall/en/WW/Catalog/Product/6SL3210-1KE12-3UF2 | 2026-08-02 | =FC01+CP01-U100
-U101 | Pump drive | Siemens | SINAMICS G120C PN 0.75 kW unfiltered | 6SL3210-1KE12-3UF2 | 1 | Provisional | Startdrive selection open | 73 | 196 | 225.4 | SELECTED ENVELOPE; drive rating/duty and Startdrive configuration remain provisional | https://mall.industry.siemens.com/mall/en/WW/Catalog/Product/6SL3210-1KE12-3UF2 | 2026-08-02 | =FC01+CP01-U101
-SW100 | Managed Ethernet switch | Siemens | SCALANCE XC208 managed | 6GK5208-0BA00-2AC2 | 1 | Selected network baseline | Native configuration open | 60 | 147 | 125 | VLAN-capable Layer 2 switch; firewall/router required for inter-zone traffic | https://support.industry.siemens.com/teddatasheet/?caller=SIOS&format=pdf&language=en&mlfbs=6GK5208-0BA00-2AC2 | 2026-08-02 | =FC01+CP01-SW100
-FW100 | Industrial firewall/router | Siemens | SCALANCE S615 EEC | 6GK5615-0AA01-2AA2 | 1 | Selected network baseline | Native configuration open | 35 | 147 | 127 | SELECTED NETWORK BASELINE — native configuration and site policy open | https://mall.industry.siemens.com/mall/en/oeii/Catalog/Product?SiepCountryCode=OE&mlfb=6GK5615-0AA01-2AA2 | 2026-08-02 | =FC01+CP01-FW100
-PC200 | Vision edge compute | NVIDIA | Jetson Orin NX 16GB on industrial carrier |  | 1 | Architecture only | JetPack/DeepStream image not selected | 115 | 165 | 80 | TBD — NOT PROCUREMENT OR CONSTRUCTION DATA; confirm industrial carrier, thermal solution, EMC and lifecycle | https://developer.nvidia.com/deepstream-sdk | 2026-08-02 | =FC01+CP01-PC200

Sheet: PLC I-O
symbol | direction | address | module | channel | device | description | safe_default | classification
SAFETY_OK | DI | I0.0 | -A102 | 0 | -K100 | Dry-contact mirror from the external safety interface; monitoring only, never a safety control channel | FALSE | Standard control
GUARD_CLOSED_STATUS | DI | I0.1 | -A102 | 1 | -S102 | Dry-contact guard-status mirror; monitoring only, never a safety control channel | FALSE | Standard control
AIR_PRESSURE_OK | DI | I0.2 | -A102 | 2 | -B100 | Pneumatic pressure switch | FALSE | Standard control
PRODUCT_SUPPLY_OK | DI | I0.3 | -A102 | 3 | -B101 | Product supply permissive | FALSE | Standard control
DI_SPARE_DRIVE_REMOVED_01 | DI | I0.4 | -A102 | 4 | SPARE | Spare channel; hardwired drive run/status removed because Standard Telegram 1 PROFINET is primary | FALSE | Standard control
DI_SPARE_DRIVE_REMOVED_02 | DI | I0.5 | -A102 | 5 | SPARE | Spare channel; hardwired drive run/status removed because Standard Telegram 1 PROFINET is primary | FALSE | Standard control
DI_SPARE_DRIVE_REMOVED_03 | DI | I0.6 | -A102 | 6 | SPARE | Spare channel; hardwired drive run/status removed because Standard Telegram 1 PROFINET is primary | FALSE | Standard control
DI_SPARE_DRIVE_REMOVED_04 | DI | I0.7 | -A102 | 7 | SPARE | Spare channel; hardwired drive run/status removed because Standard Telegram 1 PROFINET is primary | FALSE | Standard control
DI_SPARE_DRIVE_REMOVED_05 | DI | I1.0 | -A102 | 8 | SPARE | Spare channel; hardwired drive run/status removed because Standard Telegram 1 PROFINET is primary | FALSE | Standard control
DI_SPARE_DRIVE_REMOVED_06 | DI | I1.1 | -A102 | 9 | SPARE | Spare channel; hardwired drive run/status removed because Standard Telegram 1 PROFINET is primary | FALSE | Standard control
BOTTLE_AT_NEST_1 | DI | I1.2 | -A102 | 10 | -B110 | Bottle 1 position sensor | FALSE | Standard control
BOTTLE_AT_NEST_2 | DI | I1.3 | -A102 | 11 | -B111 | Bottle 2 position sensor | FALSE | Standard control
GATE_OPEN_FB | DI | I1.4 | -A102 | 12 | -B120 | Gate open feedback | FALSE | Standard control
GATE_CLOSED_FB | DI | I1.5 | -A102 | 13 | -B121 | Gate closed feedback | FALSE | Standard control
CLAMP_RELEASED_FB | DI | I1.6 | -A102 | 14 | -B122 | Clamp released feedback | FALSE | Standard control
CLAMP_ENGAGED_FB | DI | I1.7 | -A102 | 15 | -B123 | Clamp engaged feedback | FALSE | Standard control
FILL_VALVE_1_CLOSED_FB | DI | I2.0 | -A102 | 16 | -B130 | Valve 1 closed proof | FALSE | Standard control
FILL_VALVE_2_CLOSED_FB | DI | I2.1 | -A102 | 17 | -B131 | Valve 2 closed proof | FALSE | Standard control
CAPPER_READY | DI | I2.2 | -A102 | 18 | -IF140 | Capping station ready | FALSE | Standard control
CAPPER_BUSY | DI | I2.3 | -A102 | 19 | -IF140 | Capping station busy | FALSE | Standard control
CAPPER_COMPLETE | DI | I2.4 | -A102 | 20 | -IF140 | Capping complete acknowledgement | FALSE | Standard control
CAPPER_FAULT | DI | I2.5 | -A102 | 21 | -IF140 | Capping fault | FALSE | Standard control
LOCAL_RESET_PB | DI | I2.6 | -A102 | 22 | -S100 | Local reset pushbutton | FALSE | Standard control
LOCAL_STOP_PB | DI | I2.7 | -A102 | 23 | -S101 | Local controlled-stop pushbutton | FALSE | Standard control
DI_SPARE_01 | DI | I3.0 | -A102 | 24 | SPARE | Allocated spare input | FALSE | Standard control
DI_SPARE_02 | DI | I3.1 | -A102 | 25 | SPARE | Allocated spare input | FALSE | Standard control
DI_SPARE_03 | DI | I3.2 | -A102 | 26 | SPARE | Allocated spare input | FALSE | Standard control
DI_SPARE_04 | DI | I3.3 | -A102 | 27 | SPARE | Allocated spare input | FALSE | Standard control
DI_SPARE_05 | DI | I3.4 | -A102 | 28 | SPARE | Allocated spare input | FALSE | Standard control
DI_SPARE_06 | DI | I3.5 | -A102 | 29 | SPARE | Allocated spare input | FALSE | Standard control
DI_SPARE_07 | DI | I3.6 | -A102 | 30 | SPARE | Allocated spare input | FALSE | Standard control
DI_SPARE_08 | DI | I3.7 | -A102 | 31 | SPARE | Allocated spare input | FALSE | Standard control
DO_SPARE_DRIVE_REMOVED_01 | DO | Q0.0 | -A103 | 0 | SPARE | Spare channel; hardwired drive run/status removed because Standard Telegram 1 PROFINET is primary | FALSE | Standard control
DO_SPARE_DRIVE_REMOVED_02 | DO | Q0.1 | -A103 | 1 | SPARE | Spare channel; hardwired drive run/status removed because Standard Telegram 1 PROFINET is primary | FALSE | Standard control
FILL_VALVE_1_OPEN_CMD | DO | Q0.2 | -A103 | 2 | -K202 | Valve 1 interposing relay | FALSE | Standard control
FILL_VALVE_2_OPEN_CMD | DO | Q0.3 | -A103 | 3 | -K203 | Valve 2 interposing relay | FALSE | Standard control
GATE_OPEN_CMD | DO | Q0.4 | -A103 | 4 | -K204 | Gate open relay | FALSE | Standard control
GATE_CLOSE_CMD | DO | Q0.5 | -A103 | 5 | -K205 | Gate close relay | FALSE | Standard control
CLAMP_ENGAGE_CMD | DO | Q0.6 | -A103 | 6 | -K206 | Clamp engage relay | FALSE | Standard control
CLAMP_RELEASE_CMD | DO | Q0.7 | -A103 | 7 | -K207 | Clamp release relay | FALSE | Standard control
CAPPER_REQUEST | DO | Q1.0 | -A103 | 8 | -K208 | Capping request relay | FALSE | Standard control
STACK_GREEN | DO | Q1.1 | -A103 | 9 | -K209 | Green beacon relay | FALSE | Standard control
STACK_AMBER | DO | Q1.2 | -A103 | 10 | -K210 | Amber beacon relay | FALSE | Standard control
STACK_RED | DO | Q1.3 | -A103 | 11 | -K211 | Red beacon relay | FALSE | Standard control
AUDIBLE_ALARM | DO | Q1.4 | -A103 | 12 | -K212 | Sounder relay | FALSE | Standard control
CAMERA_LIGHT_ENABLE | DO | Q1.5 | -A103 | 13 | -K213 | Vision lighting relay | FALSE | Standard control
DO_SPARE_01 | DO | Q1.6 | -A103 | 14 | SPARE | Allocated spare output | FALSE | Standard control
DO_SPARE_02 | DO | Q1.7 | -A103 | 15 | SPARE | Allocated spare output | FALSE | Standard control
DO_SPARE_03 | DO | Q2.0 | -A103 | 16 | SPARE | Allocated spare output | FALSE | Standard control
DO_SPARE_04 | DO | Q2.1 | -A103 | 17 | SPARE | Allocated spare output | FALSE | Standard control
DO_SPARE_05 | DO | Q2.2 | -A103 | 18 | SPARE | Allocated spare output | FALSE | Standard control
DO_SPARE_06 | DO | Q2.3 | -A103 | 19 | SPARE | Allocated spare output | FALSE | Standard control
DO_SPARE_07 | DO | Q2.4 | -A103 | 20 | SPARE | Allocated spare output | FALSE | Standard control
DO_SPARE_08 | DO | Q2.5 | -A103 | 21 | SPARE | Allocated spare output | FALSE | Standard control
DO_SPARE_09 | DO | Q2.6 | -A103 | 22 | SPARE | Allocated spare output | FALSE | Standard control
DO_SPARE_10 | DO | Q2.7 | -A103 | 23 | SPARE | Allocated spare output | FALSE | Standard control
DO_SPARE_11 | DO | Q3.0 | -A103 | 24 | SPARE | Allocated spare output | FALSE | Standard control
DO_SPARE_12 | DO | Q3.1 | -A103 | 25 | SPARE | Allocated spare output | FALSE | Standard control
DO_SPARE_13 | DO | Q3.2 | -A103 | 26 | SPARE | Allocated spare output | FALSE | Standard control
DO_SPARE_14 | DO | Q3.3 | -A103 | 27 | SPARE | Allocated spare output | FALSE | Standard control
DO_SPARE_15 | DO | Q3.4 | -A103 | 28 | SPARE | Allocated spare output | FALSE | Standard control
DO_SPARE_16 | DO | Q3.5 | -A103 | 29 | SPARE | Allocated spare output | FALSE | Standard control
DO_SPARE_17 | DO | Q3.6 | -A103 | 30 | SPARE | Allocated spare output | FALSE | Standard control
DO_SPARE_18 | DO | Q3.7 | -A103 | 31 | SPARE | Allocated spare output | FALSE | Standard control
FLOW_1_MA_RAW | AI | IW64 | -A104 | 0 | -FT100 | Flow channel 1 instantaneous 4–20 mA | 0 | Standard control
FLOW_2_MA_RAW | AI | IW66 | -A104 | 1 | -FT101 | Flow channel 2 instantaneous 4–20 mA | 0 | Standard control
AI_SPARE_01 | AI | IW68 | -A104 | 2 | SPARE | Allocated spare analog input | 0 | Standard control
AI_SPARE_02 | AI | IW70 | -A104 | 3 | SPARE | Allocated spare analog input | 0 | Standard control
AI_SPARE_03 | AI | IW72 | -A104 | 4 | SPARE | Allocated spare analog input | 0 | Standard control

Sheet: Drive PZD
drive | name | telegram | direction | pzd | address | signal | data_type | scaling | status
-U100 | CONVEYOR | Standard Telegram 1 | Drive_to_PLC | 1 | IW256 | ZSW1 status word | WORD | Bit-coded per SINAMICS | Native Startdrive/TIA confirmation open
-U100 | CONVEYOR | Standard Telegram 1 | Drive_to_PLC | 2 | IW258 | NIST_A actual speed | INT | 16384 = 100% reference speed | Native Startdrive/TIA confirmation open
-U100 | CONVEYOR | Standard Telegram 1 | PLC_to_Drive | 1 | QW256 | STW1 control word | WORD | Bit-coded per SINAMICS | Native Startdrive/TIA confirmation open
-U100 | CONVEYOR | Standard Telegram 1 | PLC_to_Drive | 2 | QW258 | NSOLL_A speed setpoint | INT | 16384 = 100% reference speed | Native Startdrive/TIA confirmation open
-U101 | PUMP | Standard Telegram 1 | Drive_to_PLC | 1 | IW260 | ZSW1 status word | WORD | Bit-coded per SINAMICS | Native Startdrive/TIA confirmation open
-U101 | PUMP | Standard Telegram 1 | Drive_to_PLC | 2 | IW262 | NIST_A actual speed | INT | 16384 = 100% reference speed | Native Startdrive/TIA confirmation open
-U101 | PUMP | Standard Telegram 1 | PLC_to_Drive | 1 | QW260 | STW1 control word | WORD | Bit-coded per SINAMICS | Native Startdrive/TIA confirmation open
-U101 | PUMP | Standard Telegram 1 | PLC_to_Drive | 2 | QW262 | NSOLL_A speed setpoint | INT | 16384 = 100% reference speed | Native Startdrive/TIA confirmation open

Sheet: VFD Parameters
drive | parameter | value | status
-U100/-U101 | Primary control | PROFINET Standard Telegram 1 | Design baseline; native confirmation open
-U100/-U101 | PZD | STW1/NSOLL_A and ZSW1/NIST_A, 2 words each direction | Addresses controlled in drive interface schedule
-U100/-U101 | Scaling | Signed 16384 = 100 percent reference speed | Reference speed/motor data open
-U100/-U101 | Hardwired standard I/O | None for run/ready/running/fault | Removed from PLC physical I/O
-U100/-U101 | STO | External conceptual safety interface only | Qualified safety design required
-U100/-U101 | Ramps/current/min/max/braking/EMC | Not selected | Motor, mechanics, supply and cable inputs required

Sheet: NVIDIA Versions
domain | version | platform | status | source
DeepStream target | 9.1 | Jetson Orin/Thor or supported x86 | OFFICIAL CURRENT; target image not selected | https://docs.nvidia.com/metropolis/deepstream/9.1/text/DS_Release_notes.html
Jetson installation | JetPack 7.2 GA | Jetson | PLANNING BASELINE | https://docs.nvidia.com/metropolis/deepstream/dev-guide/text/DS_Installation.html
DeepStream Jetson TensorRT | 10.16.1.7 | Jetson | PLATFORM-SPECIFIC COMPATIBILITY | https://docs.nvidia.com/metropolis/deepstream/dev-guide/text/DS_Migration_guide.html
TAO skill bank | 7.0.1 | Approved Linux/container backend | NOT INSTALLED OR EXECUTED | https://docs.nvidia.com/tao/tao-toolkit/latest/text/release_notes.html
Generic TensorRT | 11.1 | Generic supported platforms | CURRENT GENERIC; NOT JETSON TARGET EVIDENCE | https://docs.nvidia.com/deeplearning/tensorrt/latest/getting-started/release-notes-11/11.1.0.html
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

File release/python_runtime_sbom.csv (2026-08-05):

component | version | license_metadata | role | source | status
aiosqlite | 0.22.1 | NOT DECLARED IN INSTALLED METADATA | asyncua dependency | https://pypi.org/project/aiosqlite/ | LICENCE REVIEW REQUIRED BEFORE PRODUCTION DISTRIBUTION
anyio | 4.14.2 | MIT | asyncua dependency | https://pypi.org/project/anyio/ | RECORDED
asyncua | 2.0.1 | GNU Lesser General Public License v3 or later | OPC UA client/server integration | https://pypi.org/project/asyncua/ | RECORDED
cffi | 2.1.0 | MIT-0 | cryptographic dependency | https://pypi.org/project/cffi/ | RECORDED
cryptography | 50.0.0 | Apache-2.0 OR BSD-3-Clause | X.509 and secure-channel dependency | https://pypi.org/project/cryptography/ | RECORDED
idna | 3.18 | BSD-3-Clause | network dependency | https://pypi.org/project/idna/ | RECORDED
pycparser | 3.0 | BSD-3-Clause | cffi dependency | https://pypi.org/project/pycparser/ | RECORDED
pyOpenSSL | 26.4.0 | Apache License Version 2.0 | X.509 integration dependency | https://pypi.org/project/pyOpenSSL/ | RECORDED
python-dateutil | 2.9.0.post0 | Dual License | timestamp dependency | https://pypi.org/project/python-dateutil/ | LICENCE TERMS REQUIRE PROJECT REVIEW
pytz | 2026.3.post1 | MIT | timezone dependency | https://pypi.org/project/pytz/ | RECORDED
six | 1.17.0 | MIT | compatibility dependency | https://pypi.org/project/six/ | RECORDED
sortedcontainers | 2.4.0 | Apache 2.0 | asyncua dependency | https://pypi.org/project/sortedcontainers/ | RECORDED
typing_extensions | 4.16.0 | PSF-2.0 | typing compatibility dependency | https://pypi.org/project/typing-extensions/ | RECORDED

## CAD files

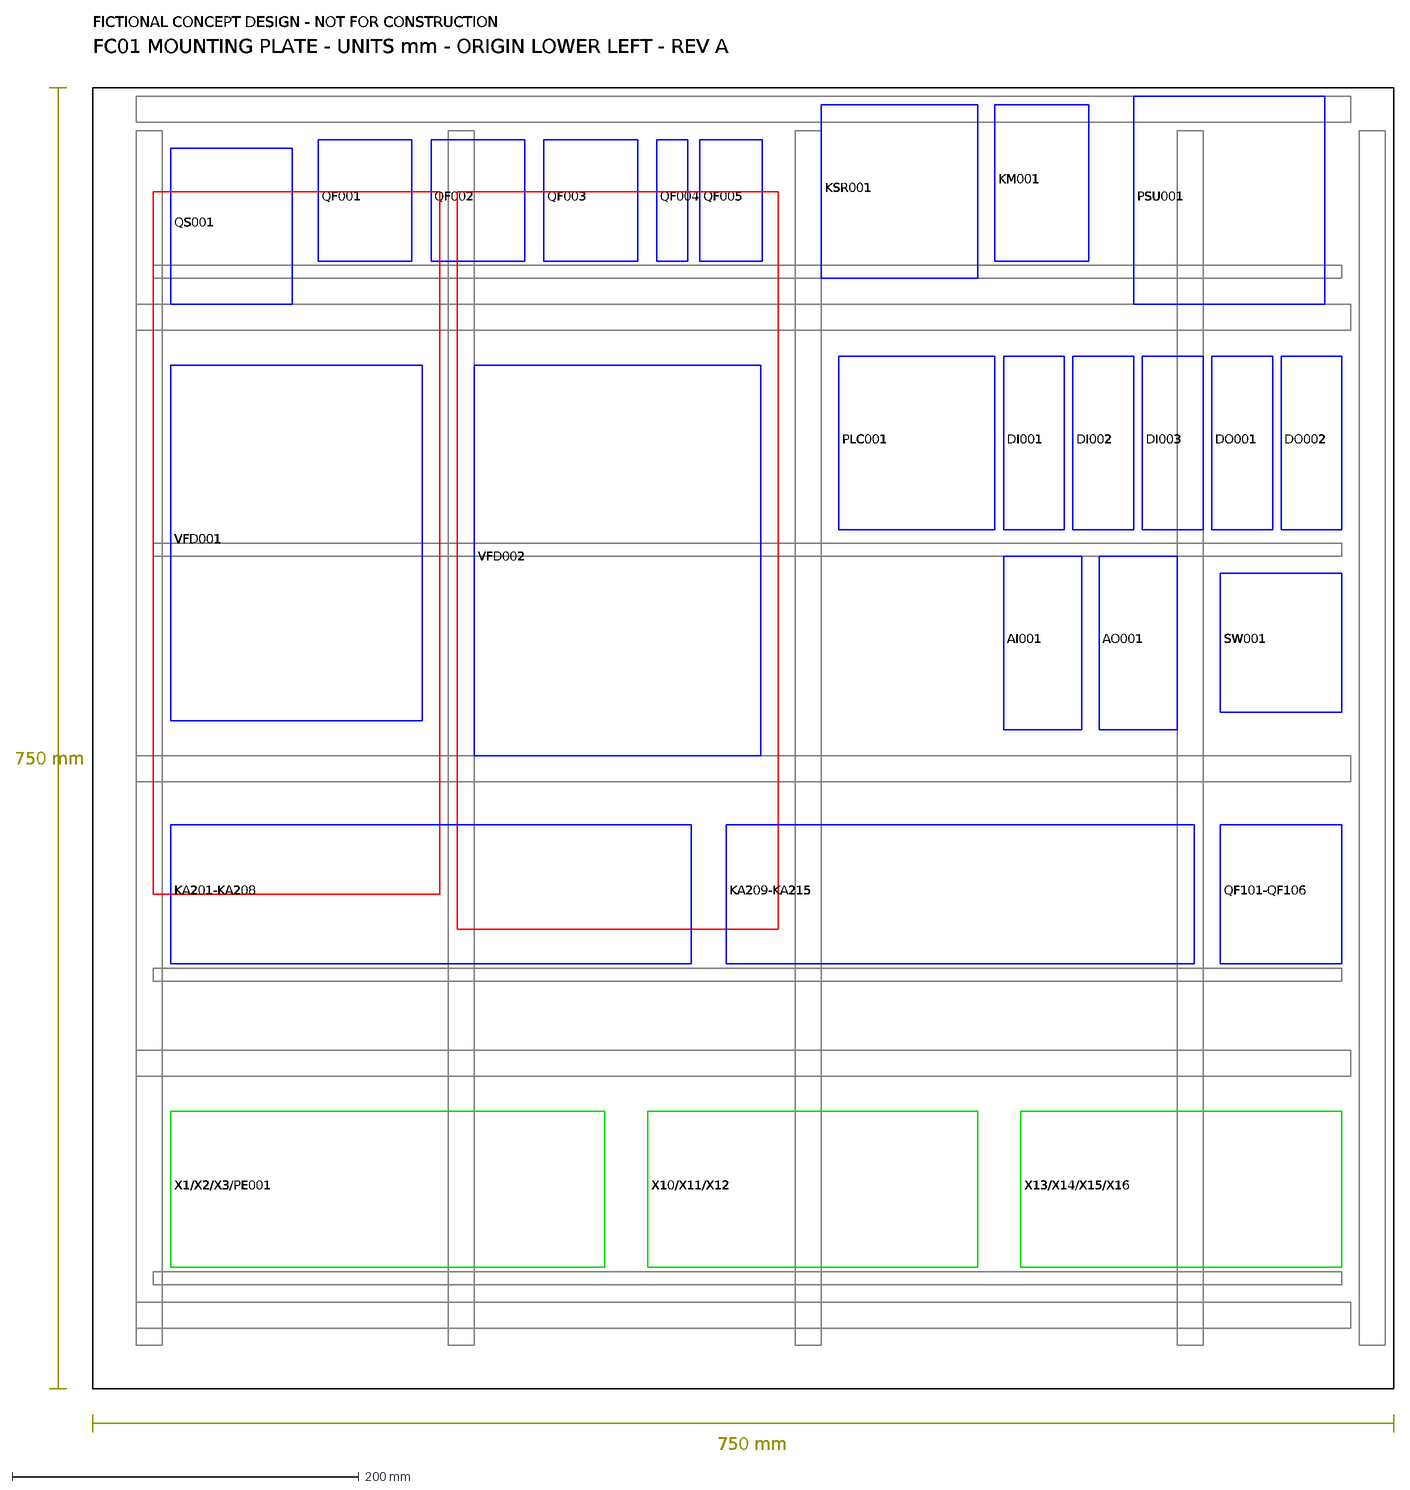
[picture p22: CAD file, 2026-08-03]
09_panel_cad/native_baseline/mounting_plate.dxf
QS001
QF001
QF002
QF003
QF004
QF005
KSR001
KM001
PSU001
VFD001
VFD002
PLC001
DI001
DI002
DI003
DO001
DO002
AI001
AO001
SW001
KA201-KA208
KA209-KA215
QF101-QF106
X1/X2/X3/PE001
X10/X11/X12
X13/X14/X15/X16
750 mm
FC01 MOUNTING PLATE - UNITS mm - ORIGIN LOWER LEFT - REV A
FICTIONAL CONCEPT DESIGN - NOT FOR CONSTRUCTION

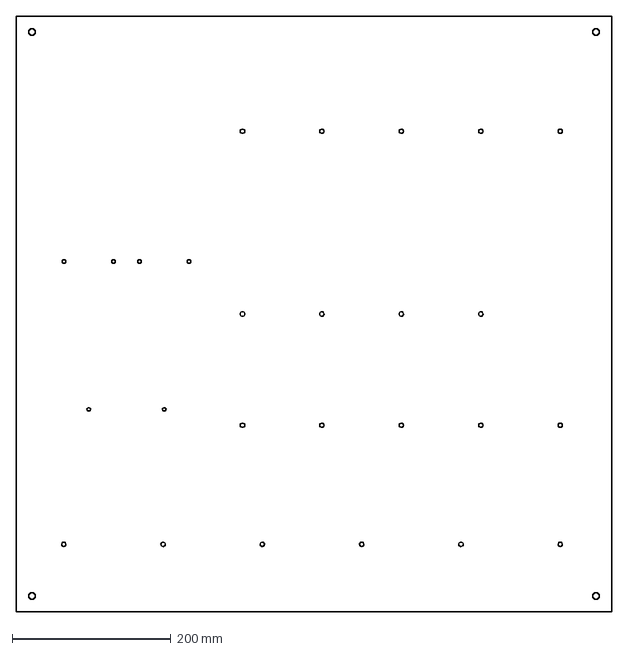
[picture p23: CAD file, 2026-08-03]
09_panel_cad/revision_e/FC01_mounting_plate_revision_e.dxf
750.0 x 750.0 mm

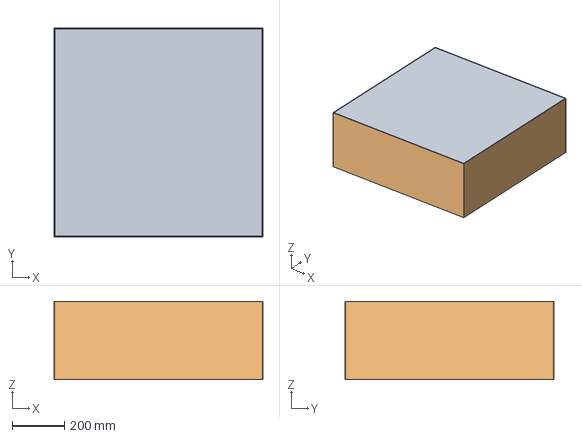
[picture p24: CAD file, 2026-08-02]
09_panel_cad/native_baseline/filling_cell_panel.step
800.0 x 800.0 x 300.0 mm

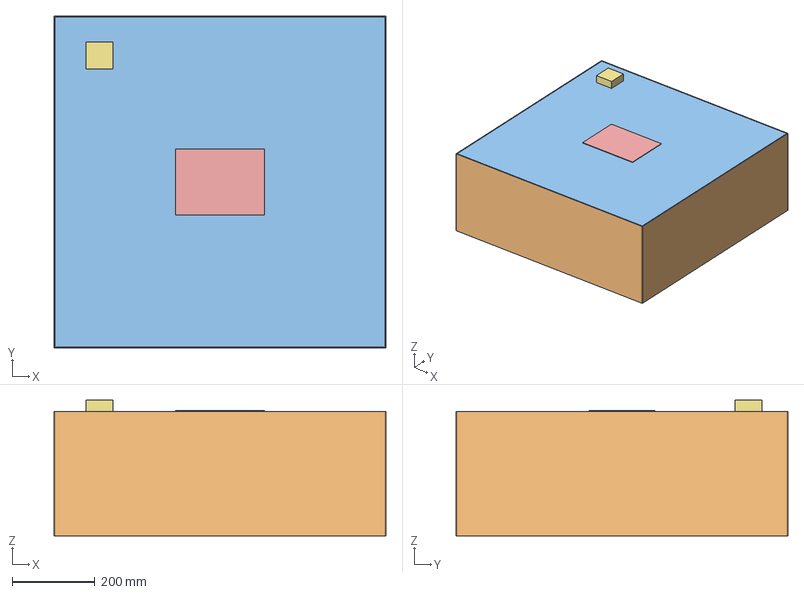
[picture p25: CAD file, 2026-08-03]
09_panel_cad/revision_e/FC01_control_panel_revision_e.step
800.0 x 800.0 x 327.0 mm
-EN100 back
-EN100 left wall
-EN100 right wall
-EN100 bottom wall
-EN100 top wall
-EN100-DR door
-MP100 drilled mounting plate
-RA100
-RA101
-RA102
-RA103
-WD100
-WD101
-WD102
-WD110
-WD111
-WD112
-WD113
-WD114
-QF100
-U100
-U101
-PS100
-QF110
-K100
-A100
-A101
-A102
-A103
-A104
-SW100
-FW100
-PC200 ASSUMED ENVELOPE
-K202
-K203
-K204
-K205
-K206
-K207
-K208
-K209
-K210
-K211
-K212
-K213
-QF111..-QF116 RESERVED
-X100:1
-X100:2
-X100:3
-X100:4
-X100:5
-X100:6
-X100:7
-X100:8
-X100:9
-X100:10
-X100:11
-X100:12
-X100:13
-X100:14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

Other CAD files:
09_panel_cad/native_baseline/filling_cell_panel.FCStd
09_panel_cad/native_baseline/filling_cell_panel.iges
09_panel_cad/revision_e/FC01_control_panel_revision_e.FCStd
09_panel_cad/revision_e/FC01_control_panel_revision_e.iges

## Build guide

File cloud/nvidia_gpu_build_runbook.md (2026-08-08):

# NVIDIA GPU build runbook

> FICTIONAL ENGINEERING PROJECT - NOT FOR CONSTRUCTION.

> CONCEPTUAL SAFETY ARCHITECTURE - REQUIRES PROJECT-SPECIFIC RISK ASSESSMENT, DESIGN, VERIFICATION AND VALIDATION BY A QUALIFIED MACHINERY-SAFETY ENGINEER. NO PERFORMANCE LEVEL, SIL, CATEGORY, CE/UKCA CONFORMITY OR REGULATORY COMPLIANCE IS CLAIMED.

1. Confirm current DeepStream/TAO compatibility and selected model requirements before selecting G2/L4 or another GPU.
2. Require an approved plan, quota and price record. Use Spot only for resumable jobs.
3. Provision Ubuntu 24.04 with no external IP; connect through IAP SSH.
4. Install the NVIDIA driver/container stack strictly from official repositories; record version/digest and licence acceptance owner.
5. Pull only an approved digest-pinned DeepStream/TAO image. Generate SBOM and vulnerability report before execution.
6. Mount controlled dataset/artifact storage least-privilege; never embed credentials in an image.
7. Run data validation, synthetic smoke, then approved real training/evaluation. Record raw logs and hashes.
8. Stop the GPU immediately after each job; verify instance state and continuing storage costs.

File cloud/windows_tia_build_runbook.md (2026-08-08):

# Windows TIA build runbook

> FICTIONAL ENGINEERING PROJECT - NOT FOR CONSTRUCTION.

> CONCEPTUAL SAFETY ARCHITECTURE - REQUIRES PROJECT-SPECIFIC RISK ASSESSMENT, DESIGN, VERIFICATION AND VALIDATION BY A QUALIFIED MACHINERY-SAFETY ENGINEER. NO PERFORMANCE LEVEL, SIL, CATEGORY, CE/UKCA CONFORMITY OR REGULATORY COMPLIANCE IS CLAIMED.

1. Confirm the selected host/virtualization route is supported by Siemens or obtain written support confirmation.
2. Provision only after approved Terraform plan and cost/security review.
3. Connect through IAP; do not add an external IP or public RDP rule.
4. Patch Windows; install Git/evidence tooling from approved sources.
5. Install TIA V20, STEP 7 Professional, WinCC Unified, Startdrive, PLCSIM and TIA Openness under the organisation licence process.
6. Assign licences without placing keys in Git/logs. Add the engineer to Siemens TIA Openness and re-authenticate.
7. Clone the exact Revision-G commit, run `siemens_native/preflight.ps1`, then follow the existing TIA/WinCC/Startdrive runbooks.
8. Store raw native logs/screenshots/archives only in the controlled evidence path; hash every artifact.
9. Stop the VM after exporting evidence; retain only approved disks/snapshots.

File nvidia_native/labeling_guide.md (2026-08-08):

# Vision labeling guide

> FICTIONAL ENGINEERING PROJECT - NOT FOR CONSTRUCTION.

> CONCEPTUAL SAFETY ARCHITECTURE - REQUIRES PROJECT-SPECIFIC RISK ASSESSMENT, DESIGN, VERIFICATION AND VALIDATION BY A QUALIFIED MACHINERY-SAFETY ENGINEER. NO PERFORMANCE LEVEL, SIL, CATEGORY, CE/UKCA CONFORMITY OR REGULATORY COMPLIANCE IS CLAIMED.

Annotators shall label each bottle channel independently: `PRESENT_OK`, `MISSING`, `MISPOSITIONED`, `WRONG_TYPE`; fill `UNDER`, `WITHIN_TOLERANCE`, `OVER`, `OBSCURED`; leakage `NONE`, `PRESENT`, `UNCERTAIN`; cap/transfer `NOT_OBSERVED`, `OK`, `FAIL`, `UNCERTAIN`. `UNCERTAIN`, occluded or contradictory labels can never be mapped to automatic PASS. Record annotator and review state outside image filenames. Double review and adjudicate all test/challenge data and every candidate false pass. Lot/session groups may not cross dataset splits.

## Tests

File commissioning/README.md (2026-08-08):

# Commissioning package boundary

> FICTIONAL ENGINEERING PROJECT - NOT FOR CONSTRUCTION.

> CONCEPTUAL SAFETY ARCHITECTURE - REQUIRES PROJECT-SPECIFIC RISK ASSESSMENT, DESIGN, VERIFICATION AND VALIDATION BY A QUALIFIED MACHINERY-SAFETY ENGINEER. NO PERFORMANCE LEVEL, SIL, CATEGORY, CE/UKCA CONFORMITY OR REGULATORY COMPLIANCE IS CLAIMED.

These procedures and records are controlled **blank templates**. They do not prove construction, FAT, SAT, calibration, energization, commissioning or approval. Actual values require calibrated instruments, named testers/witnesses and project authorization. Do not prefill pass/fail, actual values, serial numbers, dates or signatures.

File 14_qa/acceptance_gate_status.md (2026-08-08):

# Acceptance gate status - Revision G

> FICTIONAL ENGINEERING PROJECT - NOT FOR CONSTRUCTION.

> CONCEPTUAL SAFETY ARCHITECTURE - REQUIRES PROJECT-SPECIFIC RISK ASSESSMENT, DESIGN, VERIFICATION AND VALIDATION BY A QUALIFIED MACHINERY-SAFETY ENGINEER. NO PERFORMANCE LEVEL, SIL, CATEGORY, CE/UKCA CONFORMITY OR REGULATORY COMPLIANCE IS CLAIMED.

- Gate 1: **PARTIAL** - Requirements/interfaces traceable: Revision-G requirements, execution gates and evidence are traceable; owner and qualified-human approvals remain absent
- Gate 2: **PARTIAL** - Canonical model reconciles schedules: Core authorities reconcile; the Revision-F NVIDIA electrical delta remains provisional and outside final QET/CAD/construction authorities
- Gate 3: **PARTIAL** - Siemens hardware baseline confirmed: TIA V20/Openness installation is inventoried exactly; authorized native catalog confirmation and delivered hardware remain open
- Gate 4: **BLOCKED** - Native TIA project opens: TIA V20 exists but no licensed/Openness-authorized session or genuine AP20 project was available
- Gate 5: **BLOCKED** - Native TIA archive restores: No genuine ZAP20 archive exists; no native archive was fabricated
- Gate 6: **BLOCKED** - PLC compiles zero errors: 99 Siemens/source/simulator contract tests pass; native TIA compile was not run
- Gate 7: **BLOCKED** - HMI compiles zero errors: HMI definitions are controlled; native WinCC Unified compile/usability review was not run
- Gate 8: **BLOCKED** - Startdrive configured/reviewed: Startdrive is absent and motor/pump/site data remain unconfirmed
- Gate 9: **BLOCKED** - PLCSIM traces pass: PLCSIM/PLCSIM Advanced are absent; Python evidence is independent and explicitly non-native
- Gate 10: **PARTIAL** - Revision-E QET reopens and reconciles: Inherited exact-hash 26-folio QET reopen remains valid; executable was not found for a new Revision-G execution and automatic cross-references remain unsupported
- Gate 11: **PARTIAL** - Schematics export and all-page visual review: Inherited 26-page native export was reviewed; folio 25 clipping/density limitation remains open
- Gate 12: **PASS** - Revision-E FCStd reopens: FreeCADCmd 1.1.3 re-executed in Revision G: 165 objects, 148 solids, zero invalid shapes
- Gate 13: **PASS** - STEP/IGES/DXF reimport: Revision-G FreeCAD execution reimported STEP/IGES/DXF and reconciled 30 mounting holes
- Gate 14: **PARTIAL** - Full BOM/panel layout reconcile: Revision-E CAD remains natively verified; final selected vision envelopes and electrical delta incorporation remain open
- Gate 15: **BLOCKED** - Electrical calculations confirmed: Supply, earthing, fault current, motor/pump, routes, installation, ambient and enclosure inputs remain absent
- Gate 16: **BLOCKED** - Real NVIDIA dataset controlled: Dataset acquisition/labeling/schema tooling is controlled; representative real data is absent
- Gate 17: **BLOCKED** - Genuine model training/evaluation: Training/evaluation configuration is ready; no approved dataset, training run, model or metric exists
- Gate 18: **BLOCKED** - TensorRT/DeepStream target runtime: RTX 5060 driver query passed; CUDA, Docker, TAO, TensorRT, DeepStream and target Jetson/cloud runtime are absent
- Gate 19: **PARTIAL** - PLC-NVIDIA failure tests: Fail-closed edge/OPC UA/harness/synthetic-authorization tests pass; production S7/Jetson endpoint and physical timing remain unverified
- Gate 20: **OPEN** - FAT/SAT/commissioning: G3A procedures and blank records are issued; no FAT, SAT or commissioning measurement was executed
- Gate 21: **BLOCKED** - Qualified safety activities: Conceptual boundary and handoff exist; qualified machinery-safety/electrical verification and validation were not performed
- Gate 22: **PASS** - Manifest independently verifies: Published candidate 38ab54deace5e6b71479bb4a347cd39c0233f37d reproduced from a fresh GitHub clone: manifest 504/504, zero discrepancies; see DOC-G-015

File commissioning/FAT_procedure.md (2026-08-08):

# Factory acceptance test procedure

> FICTIONAL ENGINEERING PROJECT - NOT FOR CONSTRUCTION.

> CONCEPTUAL SAFETY ARCHITECTURE - REQUIRES PROJECT-SPECIFIC RISK ASSESSMENT, DESIGN, VERIFICATION AND VALIDATION BY A QUALIFIED MACHINERY-SAFETY ENGINEER. NO PERFORMANCE LEVEL, SIL, CATEGORY, CE/UKCA CONFORMITY OR REGULATORY COMPLIANCE IS CLAIMED.

Hold points: approved drawings/BOM; mechanical inspection; point-to-point wiring; PE continuity; insulation resistance under an approved isolation method; polarity/short-circuit inspection; torque/protection verification; controlled power-up; PLC diagnostics; I/O checkout; drives/motors; dosing calibration; HMI/alarms; communications/AI failure behavior; backup/restore; punch closure. Each test records instrument, serial/calibration status, point, expected/actual result, pass/fail, tester, witness, date and comments. Safety circuits and energised tests require competent persons and approved risk controls.

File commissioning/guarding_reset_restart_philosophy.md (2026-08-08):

# Conceptual guarding, reset and restart philosophy

> FICTIONAL ENGINEERING PROJECT - NOT FOR CONSTRUCTION.

> CONCEPTUAL SAFETY ARCHITECTURE - REQUIRES PROJECT-SPECIFIC RISK ASSESSMENT, DESIGN, VERIFICATION AND VALIDATION BY A QUALIFIED MACHINERY-SAFETY ENGINEER. NO PERFORMANCE LEVEL, SIL, CATEGORY, CE/UKCA CONFORMITY OR REGULATORY COMPLIANCE IS CLAIMED.

Guards, emergency-stop devices and hazardous-energy isolation are external conceptual safety provisions and are not implemented by the standard PLC or NVIDIA subsystem. Loss of power, safety status, communications or AI availability removes or withholds process commands. Restoration never starts motion. A reset clears only eligible diagnostics and returns the coordinator to STOPPED; a separate authorized start request plus all validated permissives is required. Guard reset location, visibility, escape prevention, unexpected-start risk, energy isolation and drive stop behavior require project-specific qualified design.

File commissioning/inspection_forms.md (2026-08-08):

# Inspection forms index

> FICTIONAL ENGINEERING PROJECT - NOT FOR CONSTRUCTION.

> CONCEPTUAL SAFETY ARCHITECTURE - REQUIRES PROJECT-SPECIFIC RISK ASSESSMENT, DESIGN, VERIFICATION AND VALIDATION BY A QUALIFIED MACHINERY-SAFETY ENGINEER. NO PERFORMANCE LEVEL, SIL, CATEGORY, CE/UKCA CONFORMITY OR REGULATORY COMPLIANCE IS CLAIMED.

Use `physical_test_records.csv` for incoming/BOM, mechanical, point-to-point, PE continuity, insulation, polarity, short-circuit, torque, protection, power-up, diagnostics, I/O, sensor, solenoid, motor/VFD, dosing, HMI, alarm, network/AI failure and backup/restore evidence. Use dedicated calibration, I/O, punch and redline registers for traceability. Every actual/result/signature field is intentionally blank at issue.

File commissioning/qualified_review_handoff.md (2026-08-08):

# Qualified electrical and machinery-safety review handoff

> FICTIONAL ENGINEERING PROJECT - NOT FOR CONSTRUCTION.

> CONCEPTUAL SAFETY ARCHITECTURE - REQUIRES PROJECT-SPECIFIC RISK ASSESSMENT, DESIGN, VERIFICATION AND VALIDATION BY A QUALIFIED MACHINERY-SAFETY ENGINEER. NO PERFORMANCE LEVEL, SIL, CATEGORY, CE/UKCA CONFORMITY OR REGULATORY COMPLIANCE IS CLAIMED.

Provide the functional design, hazard list, risk assumptions, electrical/QET/CAD sources, protective-device basis, calculations, safety-function list, reset/restart philosophy, commissioning records and open decisions to named competent reviewers. The qualified machinery-safety engineer owns risk assessment, safety design, PL/SIL/category determination if applicable, verification and validation. The qualified electrical engineer owns site/construction calculations and inspection acceptance. Software-agent review is not certification or approval.

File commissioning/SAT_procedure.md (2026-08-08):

# Site acceptance test procedure

> FICTIONAL ENGINEERING PROJECT - NOT FOR CONSTRUCTION.

> CONCEPTUAL SAFETY ARCHITECTURE - REQUIRES PROJECT-SPECIFIC RISK ASSESSMENT, DESIGN, VERIFICATION AND VALIDATION BY A QUALIFIED MACHINERY-SAFETY ENGINEER. NO PERFORMANCE LEVEL, SIL, CATEGORY, CE/UKCA CONFORMITY OR REGULATORY COMPLIANCE IS CLAIMED.

Confirm site supply/earthing/fault-current/environment and as-installed routes before energization. Repeat safety-critical electrical inspections, network names/IPs, field I/O, sensor alignment, motor direction, pump calibration, fill repeatability, alarm/communications failures, AI timeout/uncertainty holds, recovery without automatic restart, backup/restore and owner training. SAT acceptance requires signed measured records and punch closure; this template contains none.

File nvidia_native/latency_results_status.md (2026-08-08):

# Latency and throughput evidence status

> FICTIONAL ENGINEERING PROJECT - NOT FOR CONSTRUCTION.

> CONCEPTUAL SAFETY ARCHITECTURE - REQUIRES PROJECT-SPECIFIC RISK ASSESSMENT, DESIGN, VERIFICATION AND VALIDATION BY A QUALIFIED MACHINERY-SAFETY ENGINEER. NO PERFORMANCE LEVEL, SIL, CATEGORY, CE/UKCA CONFORMITY OR REGULATORY COMPLIANCE IS CLAIMED.

No production latency or throughput measurement exists. Local synthetic timing and the RTX driver query do not represent camera acquisition, preprocessing, model inference, publication, PLC scan timing or target Jetson/cloud execution. Record monotonic end-to-end distributions, warm-up policy, batch size, input dimensions, target hardware, power mode, container/model/config hashes and process-timeout comparison only after native execution.

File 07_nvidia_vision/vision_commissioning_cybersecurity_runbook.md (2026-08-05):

# FC01 vision commissioning, maintenance and cybersecurity runbook

> FICTIONAL ENGINEERING PROJECT — NOT FOR CONSTRUCTION

> CONCEPTUAL SAFETY ARCHITECTURE — REQUIRES PROJECT-SPECIFIC RISK ASSESSMENT, DESIGN, VERIFICATION AND VALIDATION BY A QUALIFIED MACHINERY-SAFETY ENGINEER. NO PERFORMANCE LEVEL, SIL, CATEGORY, CE CONFORMITY OR REGULATORY COMPLIANCE IS CLAIMED.

This procedure is prepared for external execution; it is not FAT, SAT or commissioning evidence.

## Optical commissioning

1. Isolate the machine under the approved site procedure. Verify enclosure, bracket, lens lock, protective window, cable strain relief, service access and lighting thermal limits.
2. Mount a traceable calibration target at every bottle plane. Record camera, lens, filter, light, firmware and bracket IDs; working distance; field width/height; pixel/mm; distortion residual; focus metric; aperture; exposure; gain and strobe timing.
3. Confirm both bottle envelopes plus at least 10% framing margin. Measure worst-case motion blur, trigger-to-exposure jitter and depth of field. Lock focus/aperture and mark tamper positions.
4. Challenge clear/colored liquids, glare, foam, labels, bottle lots, background, condensation, contamination, misalignment, empty nests and spill evidence. A failed or ambiguous image-quality criterion prevents readiness.
5. Freeze `CALIBRATION_ID`, store calibration source and hash, set the PLC expected identity, and verify a wrong identity produces HOLD.

Image acceptance: no saturation at the fill boundary beyond the validated mask; both bottle ROIs wholly visible; required pixel density met; distortion residual within the validated bound; exposure margin at line-rate; no flicker/beating; repeatable trigger; focus metric above its controlled limit; and no unreviewed occlusion.

## Software, network and trust boundary

The edge belongs to the OT quality zone. It initiates TCP 4840 only to the PLC OPC UA server. Engineering/maintenance access traverses an approved jump path; health endpoints stay loopback-only. Deny inbound services by default. Use a non-login least-privilege account, read-only application files, external writable log/state directories, secure boot/disk controls where required, signed updates, allowlisted egress and centralized time/log monitoring.

Issue distinct application and user X.509 certificates from the site CA. Disable anonymous OPC UA. Restrict the identity to read PLC-owned and write NVIDIA-owned nodes. Protect private keys, load CRLs, monitor expiry and test revocation. Never put credentials, certificates, images or product data in Git or routine logs.

Before enable: verify package/config/model/dataset/calibration/SBOM hashes; `pip check`; all 47 NodeIds/types/directions/access; NTP/PTP offset; firewall; disk reserve; log rotation; GPU/camera health; PLC/HMI alarms; safe HOLD behavior; backup; and rollback. Record every version and responsible approver.

## Fault injection and recovery

Execute with hazardous motion disabled first, then under the qualified test plan: valid pass/fail/hold; timeout/late completion; heartbeat freeze/regression/wrap; camera removal; model absent/wrong hash; dataset/calibration mismatch; malformed/contradictory result; stale/duplicate/future/reordered IDs; trigger missed; result tamper; wrong ACK; OPC UA loss/reconnect; edge/PLC restart; recipe change; UTC clock step; log/disk failure; corrupt config; queue attempt; maintenance/bypass request; certificate expiry/revocation; thermal/load soak. For each, prove no edge command energizes an actuator, no invalid result becomes PASS, IDs remain correlated, restart does not start motion, and diagnostics identify first cause.

Recovery always puts production under PLC HOLD, records the affected ID/product, restores health/identity/time, performs disabled session synchronization and requires the documented operator disposition. No buffered image/result is assigned to another bottle. No automatic production restart is permitted.

## Maintenance, backup and replacement

Back up only controlled source/config, signed model bundle, public certificates/trust lists, calibration sources, manifests and release evidence; private-key backup follows site PKI rules. Test restore on an isolated spare. Camera/lens/light/bracket replacement invalidates calibration until optical acceptance is repeated. Model or threshold changes require a new immutable ID and full promotion evidence. Retention duration, image privacy classification and incident export destination remain site decisions.

External closure needs real hardware, licensed native Siemens execution, site PKI/network authority, approved model/data, qualified machinery-safety review and witnessed commissioning.

THE NVIDIA VISION SUBSYSTEM IS NON-SAFETY-RELATED AND MUST NOT BE USED AS THE SOLE MEANS OF PERSONNEL PROTECTION, SAFE STOP, GUARD MONITORING OR HAZARDOUS-MOTION CONTROL.

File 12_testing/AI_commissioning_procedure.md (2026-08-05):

# NVIDIA inspection commissioning procedure - planned, not executed

> FICTIONAL ENGINEERING PROJECT — NOT FOR CONSTRUCTION

> CONCEPTUAL SAFETY ARCHITECTURE — REQUIRES PROJECT-SPECIFIC RISK ASSESSMENT, DESIGN, VERIFICATION AND VALIDATION BY A QUALIFIED MACHINERY-SAFETY ENGINEER. NO PERFORMANCE LEVEL, SIL, CATEGORY, CE CONFORMITY OR REGULATORY COMPLIANCE IS CLAIMED.

> FICTIONAL ENGINEERING PROJECT - NOT FOR CONSTRUCTION

## Prerequisites

Approved camera/lens/light/enclosure and mechanical datums; representative labeled dataset and approved model card; signed model/configuration bundle; compatible target image; calibrated references; licensed native Siemens project and compiled HMI; approved PKI, network/time services, risk controls and test product disposition.

## Execution

1. Record device serials, firmware, software/container digests, model/dataset/calibration identifiers and certificate fingerprints.
2. Verify power polarity, branch protection, PE/FE/shield termination, network ports and maintenance isolation while de-energized where required.
3. Establish camera working distance and field of view. Lock focus/aperture/mounts; verify exposure, motion blur, glare and per-bottle pixels at maximum speed.
4. Execute dark, flat-field, geometric and reference-target checks appropriate to the selected method.
5. Prove authenticated encrypted OPC UA access with least privilege and correct node ownership.
6. Run normal, boundary and negative challenge images, then every controlled fault-injection case.
7. Verify PLC HOLD/FAULT behavior, first-out diagnostics, immutable acknowledgement and no automatic restart.
8. Measure target latency, throughput, temperature, resource use and dropped frames with representative data; record raw evidence.
9. Back up the approved image, configuration, certificates, calibration and model bundle; perform an isolated restore test.

Commissioning acceptance requires signed project-specific records. This procedure is issued but has not been executed.

THE NVIDIA VISION SUBSYSTEM IS NON-SAFETY-RELATED AND MUST NOT BE USED AS THE SOLE MEANS OF PERSONNEL PROTECTION, SAFE STOP, GUARD MONITORING OR HAZARDOUS-MOTION CONTROL.

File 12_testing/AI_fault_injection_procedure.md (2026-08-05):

# NVIDIA inspection fault-injection procedure - planned and software-modeled

> FICTIONAL ENGINEERING PROJECT — NOT FOR CONSTRUCTION

> CONCEPTUAL SAFETY ARCHITECTURE — REQUIRES PROJECT-SPECIFIC RISK ASSESSMENT, DESIGN, VERIFICATION AND VALIDATION BY A QUALIFIED MACHINERY-SAFETY ENGINEER. NO PERFORMANCE LEVEL, SIL, CATEGORY, CE CONFORMITY OR REGULATORY COMPLIANCE IS CLAIMED.

The deterministic Revision-F structured behavioral fault-injection model covers 28 cases in `11_simulation/vision_fault_scenarios.json`. For each case record injected observations, exact session/inspection identity, timestamps, modeled PLC state, result/disposition, first-out diagnostic, physical commands and recovery sequence. This is software-only design evidence, not PLCSIM, HIL, FAT or physical evidence.

Required invariants are:

- the edge cannot energize an actuator or authorize hazardous motion;
- only a fresh coherent PASS can contribute to PLC transfer authorization;
- missing, stale, duplicate, future, delayed, malformed, contradictory, low-confidence or faulted data cannot become PASS;
- restart or reconnection cannot reuse a prior bottle/session result;
- pump and fill-valve commands are off for inspection fault/hold outcomes;
- reset never starts the machine; a new explicit start and, where required, new inspection are mandatory;
- diagnostics identify the initiating cause rather than a generic timeout when more specific evidence exists.

The structured behavioral fault-injection model is software-only design evidence. Repeat applicable cases in PLCSIM and then on isolated target hardware before FAT; label those records separately.

THE NVIDIA VISION SUBSYSTEM IS NON-SAFETY-RELATED AND MUST NOT BE USED AS THE SOLE MEANS OF PERSONNEL PROTECTION, SAFE STOP, GUARD MONITORING OR HAZARDOUS-MOTION CONTROL.

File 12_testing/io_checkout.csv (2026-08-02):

symbol | address | device | check | measured | result | signoff
SAFETY_OK | I0.0 | Safety relay mirror | Stimulate field and verify correct single channel
GUARD_CLOSED_STATUS | I0.1 | Guard circuit mirror | Stimulate field and verify correct single channel
AIR_PRESSURE_OK | I0.2 | -B100 | Stimulate field and verify correct single channel
PRODUCT_SUPPLY_OK | I0.3 | -B101 | Stimulate field and verify correct single channel
CONVEYOR_READY | I0.4 | -U100 | Stimulate field and verify correct single channel
CONVEYOR_RUNNING | I0.5 | -U100 | Stimulate field and verify correct single channel
CONVEYOR_FAULT | I0.6 | -U100 | Stimulate field and verify correct single channel
PUMP_READY | I0.7 | -U101 | Stimulate field and verify correct single channel
PUMP_RUNNING | I1.0 | -U101 | Stimulate field and verify correct single channel
PUMP_FAULT | I1.1 | -U101 | Stimulate field and verify correct single channel
BOTTLE_AT_NEST_1 | I1.2 | -B110 | Stimulate field and verify correct single channel
BOTTLE_AT_NEST_2 | I1.3 | -B111 | Stimulate field and verify correct single channel
GATE_OPEN_FB | I1.4 | -B120 | Stimulate field and verify correct single channel
GATE_CLOSED_FB | I1.5 | -B121 | Stimulate field and verify correct single channel
CLAMP_RELEASED_FB | I1.6 | -B122 | Stimulate field and verify correct single channel
CLAMP_ENGAGED_FB | I1.7 | -B123 | Stimulate field and verify correct single channel
FILL_VALVE_1_CLOSED_FB | I2.0 | -B130 | Stimulate field and verify correct single channel
FILL_VALVE_2_CLOSED_FB | I2.1 | -B131 | Stimulate field and verify correct single channel
CAPPER_READY | I2.2 | -IF140 | Stimulate field and verify correct single channel
CAPPER_BUSY | I2.3 | -IF140 | Stimulate field and verify correct single channel
CAPPER_COMPLETE | I2.4 | -IF140 | Stimulate field and verify correct single channel
CAPPER_FAULT | I2.5 | -IF140 | Stimulate field and verify correct single channel
LOCAL_RESET_PB | I2.6 | -S100 | Stimulate field and verify correct single channel
LOCAL_STOP_PB | I2.7 | -S101 | Stimulate field and verify correct single channel
DI_SPARE_01 | I3.0 | SPARE | Stimulate field and verify correct single channel
DI_SPARE_02 | I3.1 | SPARE | Stimulate field and verify correct single channel
DI_SPARE_03 | I3.2 | SPARE | Stimulate field and verify correct single channel
DI_SPARE_04 | I3.3 | SPARE | Stimulate field and verify correct single channel
DI_SPARE_05 | I3.4 | SPARE | Stimulate field and verify correct single channel
DI_SPARE_06 | I3.5 | SPARE | Stimulate field and verify correct single channel
DI_SPARE_07 | I3.6 | SPARE | Stimulate field and verify correct single channel
DI_SPARE_08 | I3.7 | SPARE | Stimulate field and verify correct single channel
CONVEYOR_RUN_CMD | Q0.0 | -K200 | Stimulate field and verify correct single channel
PUMP_RUN_CMD | Q0.1 | -K201 | Stimulate field and verify correct single channel
FILL_VALVE_1_OPEN_CMD | Q0.2 | -K202 | Stimulate field and verify correct single channel
FILL_VALVE_2_OPEN_CMD | Q0.3 | -K203 | Stimulate field and verify correct single channel
GATE_OPEN_CMD | Q0.4 | -K204 | Stimulate field and verify correct single channel
GATE_CLOSE_CMD | Q0.5 | -K205 | Stimulate field and verify correct single channel
CLAMP_ENGAGE_CMD | Q0.6 | -K206 | Stimulate field and verify correct single channel
CLAMP_RELEASE_CMD | Q0.7 | -K207 | Stimulate field and verify correct single channel
CAPPER_REQUEST | Q1.0 | -K208 | Stimulate field and verify correct single channel
STACK_GREEN | Q1.1 | -K209 | Stimulate field and verify correct single channel
STACK_AMBER | Q1.2 | -K210 | Stimulate field and verify correct single channel
STACK_RED | Q1.3 | -K211 | Stimulate field and verify correct single channel
AUDIBLE_ALARM | Q1.4 | -K212 | Stimulate field and verify correct single channel
CAMERA_LIGHT_ENABLE | Q1.5 | -K213 | Stimulate field and verify correct single channel
DO_SPARE_01 | Q1.6 | SPARE | Stimulate field and verify correct single channel
DO_SPARE_02 | Q1.7 | SPARE | Stimulate field and verify correct single channel
DO_SPARE_03 | Q2.0 | SPARE | Stimulate field and verify correct single channel
DO_SPARE_04 | Q2.1 | SPARE | Stimulate field and verify correct single channel
DO_SPARE_05 | Q2.2 | SPARE | Stimulate field and verify correct single channel
DO_SPARE_06 | Q2.3 | SPARE | Stimulate field and verify correct single channel
DO_SPARE_07 | Q2.4 | SPARE | Stimulate field and verify correct single channel
DO_SPARE_08 | Q2.5 | SPARE | Stimulate field and verify correct single channel
DO_SPARE_09 | Q2.6 | SPARE | Stimulate field and verify correct single channel
DO_SPARE_10 | Q2.7 | SPARE | Stimulate field and verify correct single channel
DO_SPARE_11 | Q3.0 | SPARE | Stimulate field and verify correct single channel
DO_SPARE_12 | Q3.1 | SPARE | Stimulate field and verify correct single channel
DO_SPARE_13 | Q3.2 | SPARE | Stimulate field and verify correct single channel
DO_SPARE_14 | Q3.3 | SPARE | Stimulate field and verify correct single channel
DO_SPARE_15 | Q3.4 | SPARE | Stimulate field and verify correct single channel
DO_SPARE_16 | Q3.5 | SPARE | Stimulate field and verify correct single channel
DO_SPARE_17 | Q3.6 | SPARE | Stimulate field and verify correct single channel
DO_SPARE_18 | Q3.7 | SPARE | Stimulate field and verify correct single channel
FLOW_1_MA_RAW | IW64 | -FT100 | Stimulate field and verify correct single channel
FLOW_2_MA_RAW | IW66 | -FT101 | Stimulate field and verify correct single channel
AI_SPARE_01 | IW68 | SPARE | Stimulate field and verify correct single channel
AI_SPARE_02 | IW70 | SPARE | Stimulate field and verify correct single channel
AI_SPARE_03 | IW72 | SPARE | Stimulate field and verify correct single channel
AI_SPARE_04 | IW74 | SPARE | Stimulate field and verify correct single channel
AI_SPARE_05 | IW76 | SPARE | Stimulate field and verify correct single channel
AI_SPARE_06 | IW78 | SPARE | Stimulate field and verify correct single channel
FLOW_1_PULSE | TM1.CH0.A | -FT100 | Stimulate field and verify correct single channel
FLOW_2_PULSE | TM1.CH1.A | -FT101 | Stimulate field and verify correct single channel

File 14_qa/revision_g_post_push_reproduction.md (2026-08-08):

# Revision G published-candidate reproduction

> FICTIONAL ENGINEERING PROJECT - NOT FOR CONSTRUCTION.

> CONCEPTUAL SAFETY ARCHITECTURE - REQUIRES PROJECT-SPECIFIC RISK ASSESSMENT, DESIGN, VERIFICATION AND VALIDATION BY A QUALIFIED MACHINERY-SAFETY ENGINEER. NO PERFORMANCE LEVEL, SIL, CATEGORY, CE/UKCA CONFORMITY OR REGULATORY COMPLIANCE IS CLAIMED.

## Outcome

**PASS** — commit `38ab54deace5e6b71479bb4a347cd39c0233f37d` on `codex/revision-g-native-cloud-execution` was fetched from GitHub into a new clone outside the development worktree and completed the controlled reproduction workflow with exit code 0. The clone remained clean after reproduction.

This record attests the published engineering candidate, not the later commit that contains this record. That attestation commit is reverified after publication and its outcome is reported externally without rewriting the verified commit.

## Exact evidence

| Check | Result |
|---|---:|
| Manifest | 504 controlled files; 0 discrepancies |
| Release-integrity checks | 871 passed; 0 failed |
| Engineering validator | 551 passed; 0 failed |
| Revision-F successor-aware verifier | 96 passed; 0 failed |
| Revision-G verifier | 113 passed; 0 failed |
| Siemens/simulator/source/native-contract tests | 99 passed; 0 failed |
| NVIDIA edge/OPC UA tests | 86 passed; 0 failed |
| PLC-AI interface-harness tests | 17 passed; 0 failed |
| Timed process scenarios | 32 passed; 0 failed |
| Vision fault scenarios | 28 passed; 1 intended release; 0 unsafe outputs |
| QET Revision-E static checks | 24 passed; 0 failed |
| QET Revision-F static checks | 19 passed; 0 failed |
| FreeCAD native checks | 80 passed; 0 failed |
| Deterministic outputs | 350 compared; 0 missing; 0 extra; 0 mismatched |
| Workbook | 27 sheets; 0 formula errors; visual review PASS |
| Release-evidence PDF | 6 pages; visual review PASS |

FreeCAD evidence comprised 165 document objects, 148 solids, zero invalid shapes, 148 STEP shapes, 34 DXF shapes, 30 DXF circles and 30 reconciled mounting holes. The workbook SHA-256 was `0589860dc2e5dcad681517b596ca9c347abf044937c76209a85d3b038a21565b`; the PDF SHA-256 was `71c6e60d6632a692250f0709e25436f18f6b7c35f203494900acc87f2d5f447d`.

## Boundaries

QElectroTech Revision-G native execution was not run because no executable was available; exact-hash inherited native evidence and static checks remain clearly distinguished. No native Siemens compile, WinCC compile, Startdrive work or PLCSIM run was performed. No representative dataset, trained model, production NVIDIA runtime, hardware FAT/SAT, commissioning, construction release, qualified safety validation or qualified-human approval is claimed. The review records are software-agent self-audits and are not independent professional certification.

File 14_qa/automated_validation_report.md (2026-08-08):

# Automated validation report — Revision F

Result: **PASS**

This is deterministic static/data/independent-model validation. Native QET/FreeCAD results are accepted only through separate controlled reopen/reimport evidence; this report is not TIA, WinCC, Startdrive, PLCSIM, production NVIDIA runtime/model, or physical proof.

## Passed checks

- 0 V/return commons scheduled
- 2 HSC channels allocated
- 24 VDC 25-percent demand-margin current is 15.573 A before inrush/derating
- 24 VDC subtotal reconciles without a false aggregate demand factor
- 32 DI channels allocated
- 32 DO channels allocated
- 32 scenario summaries generated
- 8 AI channels allocated
- BOM covers all I/O devices: []
- CPU/TIA V20 firmware baseline documented
- FCStd historical baseline container has 76 entries
- HMI heartbeat rationale describes fail-closed counter supervision
- HMI is door-mounted
- HMI never writes physical output symbols
- K100 safety-interface monitor has explicit supply and signal conductors
- OB1 executes root cell instance
- PLC physical addresses unique
- PLC symbols unique
- Poppler renderer version is locked
- QET historical baseline is well-formed XML
- RecipeManager owns atomic apply acceptance/rejection
- Revision-E QET contains at least 24 controlled folios
- Revision-E QET static verifier records exactly 24/24 passing checks
- Revision-E QET verification hash matches the controlled corrected source
- Revision-E QElectroTech native source is controlled
- Revision-E STEP/IGES/DXF exchange set is controlled
- Revision-E native FCStd source is controlled
- Revision-E real OPC UA integration contract present: test_missed_one_scan_request_level_fails_closed
- Revision-E real OPC UA integration contract present: test_secure_named_client_endpoint_and_atomic_acknowledged_result
- Revision-E real OPC UA integration contract present: test_unsolicited_server_side_publication_fails_closed
- S102 guard monitor has explicit dry-contact supply and signal conductors
- acceptance_gates.csv exactly derives from canonical model
- alarms.csv exactly derives from canonical model
- all BOM rows use strict full reference designations
- all analog returns reference the dedicated MANA common
- all source alarm mappings exist in canonical alarm schedule: []
- all standard output commands are assigned: []
- all writable HMI tags use DB_HMI command requests
- analog/HSC shields scheduled
- artifact-reproduction Python version is locked
- artifact-reproduction toolchain lock is Revision G
- artifact-tool version is locked
- balanced DATA_BLOCK endings: DB_CellMain.scl
- balanced DATA_BLOCK endings: DB_Global.scl
- balanced FUNCTION_BLOCK endings: FB_Actuator2Pos.scl
- balanced FUNCTION_BLOCK endings: FB_AlarmManager.scl
- balanced FUNCTION_BLOCK endings: FB_CapperInterface.scl
- balanced FUNCTION_BLOCK endings: FB_CellMain.scl
- balanced FUNCTION_BLOCK endings: FB_FillChannel.scl
- balanced FUNCTION_BLOCK endings: FB_HMICommandManager.scl
- balanced FUNCTION_BLOCK endings: FB_MachineCoordinator.scl
- balanced FUNCTION_BLOCK endings: FB_RecipeManager.scl
- balanced FUNCTION_BLOCK endings: FB_VFD.scl
- balanced FUNCTION_BLOCK endings: FB_VisionInterface.scl
- balanced ORGANIZATION_BLOCK endings: OB100_Startup.scl
- balanced ORGANIZATION_BLOCK endings: OB1_Call_Structure.scl
- blocking-fault arbitration includes AirPressureOk
- blocking-fault arbitration includes Capper.Fault
- blocking-fault arbitration includes Clamp.Fault
- blocking-fault arbitration includes CommunicationsHealthy
- blocking-fault arbitration includes Gate.Fault
- blocking-fault arbitration includes GuardClosed
- blocking-fault arbitration includes ProductSupplyOk
- blocking-fault arbitration includes Vision.Fault
- body and scheduled clearances remain inside 800 x 800 panel boundary: -A100
- body and scheduled clearances remain inside 800 x 800 panel boundary: -A101
- body and scheduled clearances remain inside 800 x 800 panel boundary: -A102
- body and scheduled clearances remain inside 800 x 800 panel boundary: -A103
- body and scheduled clearances remain inside 800 x 800 panel boundary: -A104
- body and scheduled clearances remain inside 800 x 800 panel boundary: -FW100
- body and scheduled clearances remain inside 800 x 800 panel boundary: -PC200
- body and scheduled clearances remain inside 800 x 800 panel boundary: -PE100
- body and scheduled clearances remain inside 800 x 800 panel boundary: -SW100
- body and scheduled clearances remain inside 800 x 800 panel boundary: -U100
- body and scheduled clearances remain inside 800 x 800 panel boundary: -U101
- body and scheduled clearances remain inside 800 x 800 panel boundary: -WD100
- body and scheduled clearances remain inside 800 x 800 panel boundary: -X100..-X199
- bom.csv exactly derives from canonical model
- cable/core allocations unique
- cable_schedule.csv exactly derives from canonical model
- canonical cell inputs are normalized and consumed: []
- canonical major-device coordinates, envelopes and clearances match the native Revision-E placement schedule
- canonical revision G
- capper external/handshake faults map to alarm 1402
- capper reset requires all diagnosed causes cleared
- command arbitration separated from output mapper
- complete relay coil/contact/load path: AUDIBLE_ALARM
- complete relay coil/contact/load path: CAMERA_LIGHT_ENABLE
- complete relay coil/contact/load path: CAPPER_REQUEST
- complete relay coil/contact/load path: CLAMP_ENGAGE_CMD
- complete relay coil/contact/load path: CLAMP_RELEASE_CMD
- complete relay coil/contact/load path: FILL_VALVE_1_OPEN_CMD
- complete relay coil/contact/load path: FILL_VALVE_2_OPEN_CMD
- complete relay coil/contact/load path: GATE_CLOSE_CMD
- complete relay coil/contact/load path: GATE_OPEN_CMD
- complete relay coil/contact/load path: STACK_AMBER
- complete relay coil/contact/load path: STACK_GREEN
- complete relay coil/contact/load path: STACK_RED
- complete reproduction verifies the locked artifact toolchain
- component rationale separates selection status from open evidence/blocker
- component_rationale.csv exactly derives from canonical model
- composed PLC/edge test covers rejected delayed publication cleanup and rearm
- connection mandatory fields populated
- contradictory hardwired drive run/status I/O removed
- controlled determinism report uses source-neutral authoritative-snapshot wording
- controlled hardware schedule and native CAD agree on drive, firewall and edge-compute envelopes
- current equipment faults arbitrate and permissives recompute before one-shot power-recovery reset reaches coordinator
- determinism exports authoritative index or HEAD snapshots
- determinism report is byte-identical for index and HEAD sources
- direct Revision-D interface test present: test_analog_zero_pulses_positive
- direct Revision-D interface test present: test_both_measurements_no_flow
- direct Revision-D interface test present: test_busy_ready_contradiction
- direct Revision-D interface test present: test_counter_rollover
- direct Revision-D interface test present: test_duplicate_request_id
- direct Revision-D interface test present: test_future_id
- direct Revision-D interface test present: test_pulse_zero_analog_positive
- direct Revision-D interface test present: test_reset_after_stale
- direct Revision-D interface test present: test_reset_does_not_restart
- direct Revision-D interface test present: test_result_valid_stuck_high
- direct Revision-D interface test present: test_stale_id
- direct Revision-D interface test present: test_timeout_then_delayed_result
- direct Revision-D interface test present: test_timer_boundary
- drive PZD process-image mapping present
- drive_interfaces.csv exactly derives from canonical model
- duplicate vision request cannot advance the active inspection ID
- edge config node IDs exactly match generated node map
- edge config records disabled four-counter anti-replay synchronization
- edge node map/config exactly track canonical vision signals
- edge publication remains immutable through same-session faults and records new-session invalidation
- edge rearm reuses one protected validated identity read
- edge service enforces monotonic/matched inspection IDs
- edge service is fail-closed on model identity and timed heartbeat
- edge tests cover malformed ACK and model-identity ingress
- every cable is referenced by connection records
- exact 15-file Siemens type/FB/DB/OB source inventory present
- exact notice present: 00_project_control/design_basis.md
- exact notice present: 14_qa/acceptance_gate_status.md
- exact notice present: AGENTS.md
- exact notice present: README.md
- exact notice present: release/RELEASE_NOTES.md
- exact safety boundary present: 00_project_control/design_basis.md
- exact safety boundary present: 14_qa/acceptance_gate_status.md
- exact safety boundary present: AGENTS.md
- exact safety boundary present: README.md
- exact safety boundary present: release/RELEASE_NOTES.md
- expanded panel and field BOM has at least 45 controlled lines
- explicit Git byte policy includes * text=auto eol=lf
- explicit Git byte policy includes *.FCStd    -text
- explicit Git byte policy includes *.dxf      -text
- explicit Git byte policy includes *.example  text eol=lf
- explicit Git byte policy includes *.iges     -text
- explicit Git byte policy includes *.log      text eol=lf
- explicit Git byte policy includes *.pdf      -text
- explicit Git byte policy includes *.png      -text
- explicit Git byte policy includes *.qet      -text
- explicit Git byte policy includes *.service  text eol=lf
- explicit Git byte policy includes *.step     -text
- explicit Git byte policy includes *.xlsx     -text
- explicit TM Count M/reference conductor: FLOW_1_PULSE
- explicit TM Count M/reference conductor: FLOW_2_PULSE
- external connection cable/core/terminal fields populated
- external connections use strict class-number reference designations
- external panel terminals unique
- field and relay terminals are not double-landed
- fill start/reset/post-close contract includes #FlowLMin <= #NoFlowMinLMin
- fill start/reset/post-close contract includes #scanDelta := 0; #lastPulseTotal := #PulseTotal
- fill start/reset/post-close contract includes NOT #AnalogBrokenWire
- fill start/reset/post-close contract includes NOT #closing
- fill start/reset/post-close contract includes tFlowStopped
- fill-channel implements ABORTED
- fill-channel implements ANALOG_NO_FLOW
- fill-channel implements CounterDiscontinuity
- fill-channel implements CounterRolloverObserved
- fill-channel implements MeasurementWindowValid
- fill-channel implements PULSE_COUNTER_DISCONTINUITY
- fill-channel implements PULSE_MISSING
- fill-channel implements PumpRequest
- fill-channel implements comparisonArmed
- fill-channel implements tAnalogNoFlow
- fill-channel implements tPulseMissing
- fill-channel implements tValveClose
- fresh-clone Revision-G CI workflow is controlled
- generated Siemens source parity: 00_types.scl
- generated Siemens source parity: DB_CellMain.scl
- generated Siemens source parity: DB_Global.scl
- generated Siemens source parity: FB_Actuator2Pos.scl
- generated Siemens source parity: FB_AlarmManager.scl
- generated Siemens source parity: FB_CapperInterface.scl
- generated Siemens source parity: FB_CellMain.scl
- generated Siemens source parity: FB_FillChannel.scl
- generated Siemens source parity: FB_HMICommandManager.scl
- generated Siemens source parity: FB_MachineCoordinator.scl
- generated Siemens source parity: FB_RecipeManager.scl
- generated Siemens source parity: FB_VFD.scl
- generated Siemens source parity: FB_VisionInterface.scl
- generated Siemens source parity: OB100_Startup.scl
- generated Siemens source parity: OB1_Call_Structure.scl
- guard-status mirror maps to controlled S102 dry-contact interface
- hardware and panel rows use strict full reference designations
- historical native baseline retained: 03_electrical/native_baseline/filling_cell.qet
- historical native baseline retained: 09_panel_cad/native_baseline/filling_cell_panel.FCStd
- historical native baseline retained: 09_panel_cad/native_baseline/mounting_plate.dxf
- hmi_tags.csv exactly derives from canonical model
- inherited Revision-D.1 edge regression test present: test_advanced_disabled_session_invalidates_prior_publication
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

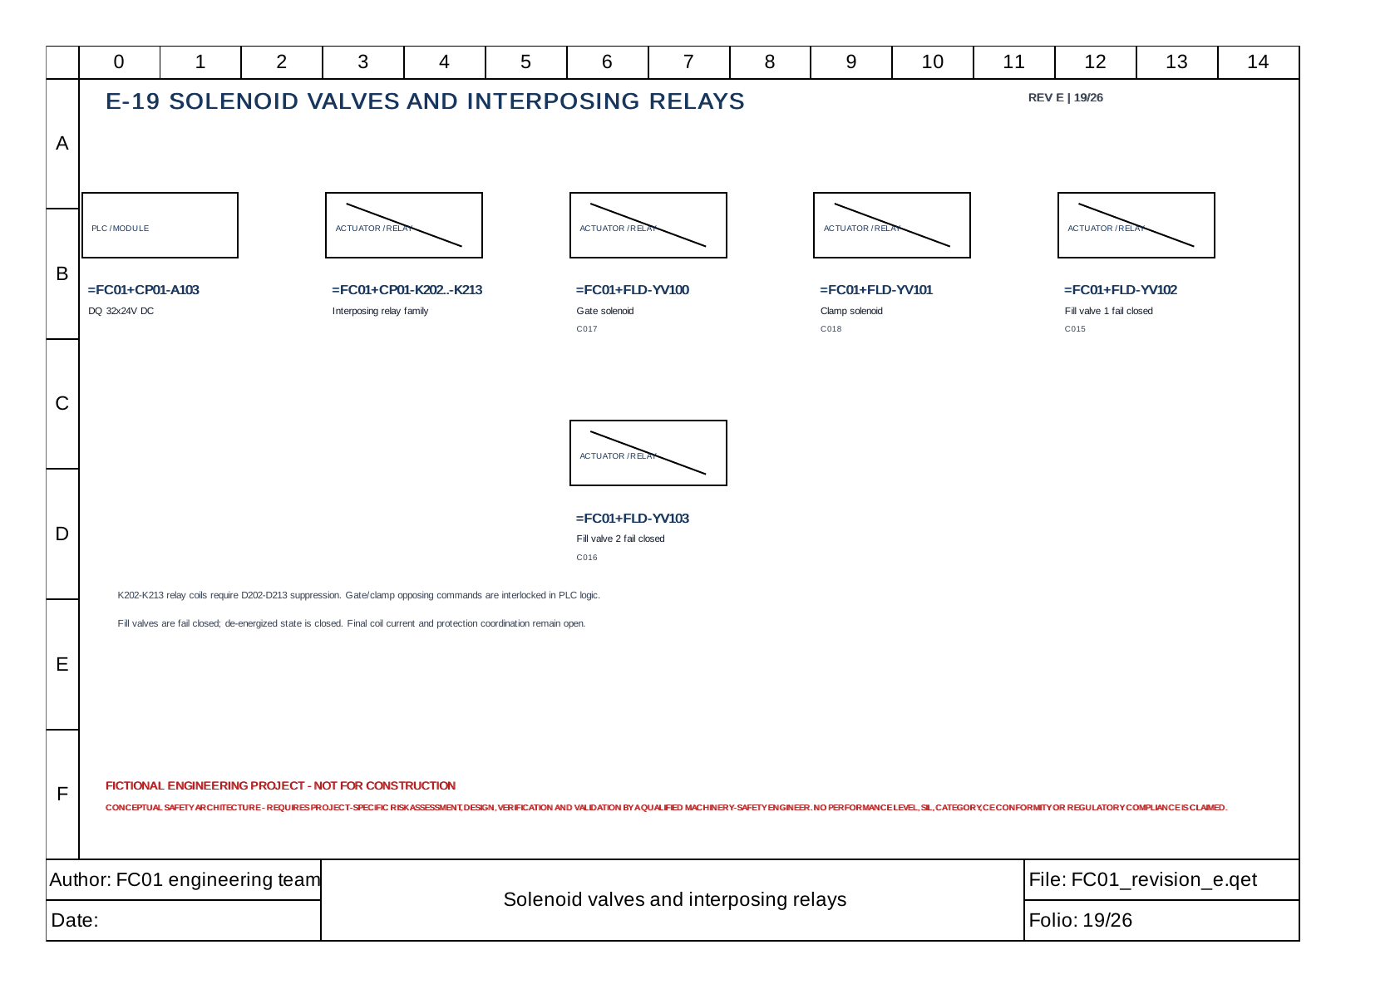
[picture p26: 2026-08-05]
14_qa/qet_revision_f_rendered/page-19.png

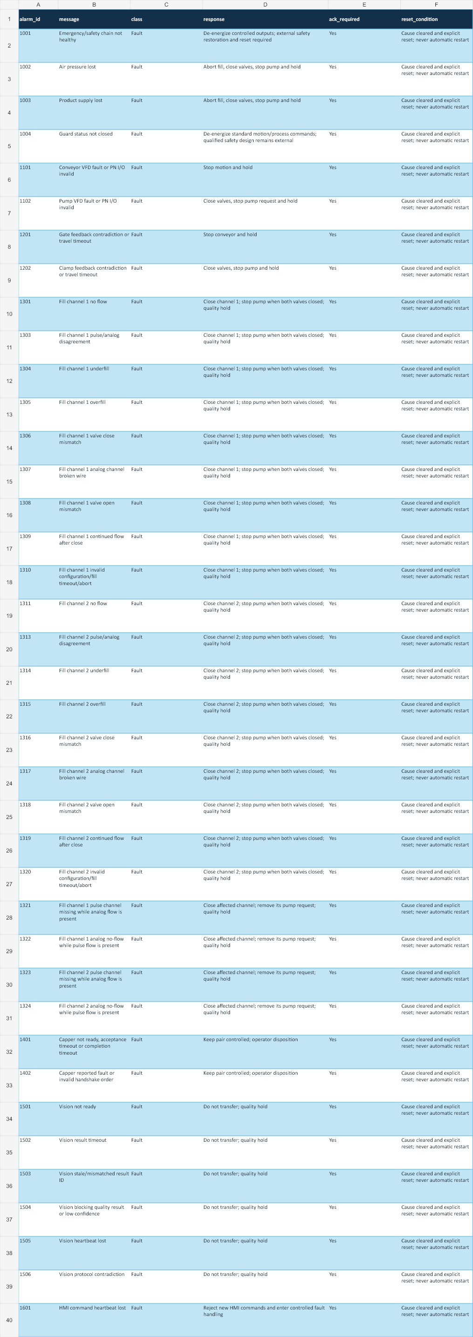
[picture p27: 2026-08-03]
14_qa/workbook_renders/alarms.png

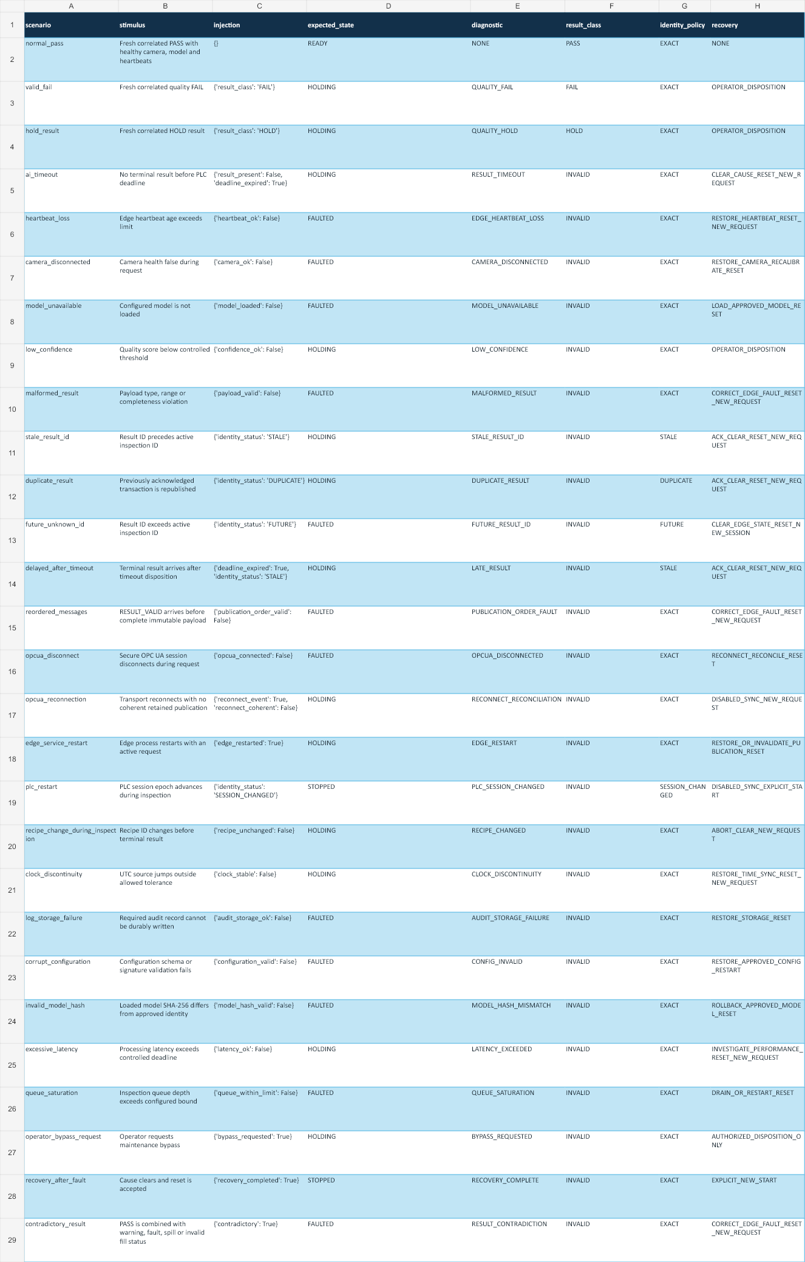
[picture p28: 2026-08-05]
14_qa/workbook_renders/vision-fault-matrix.png

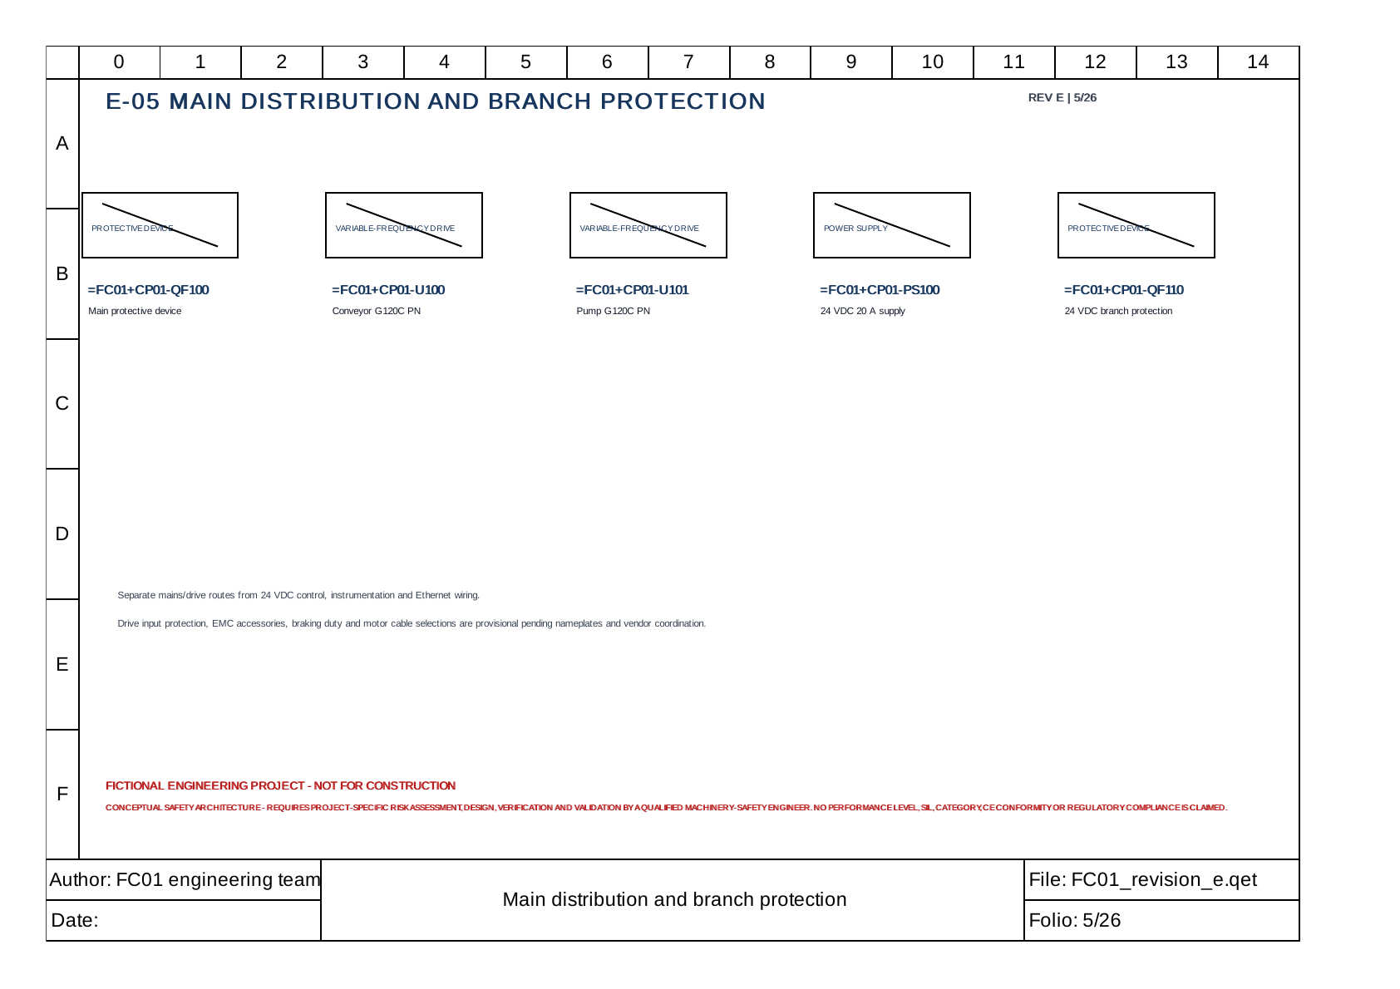
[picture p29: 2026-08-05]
14_qa/qet_revision_f_rendered/page-05.png

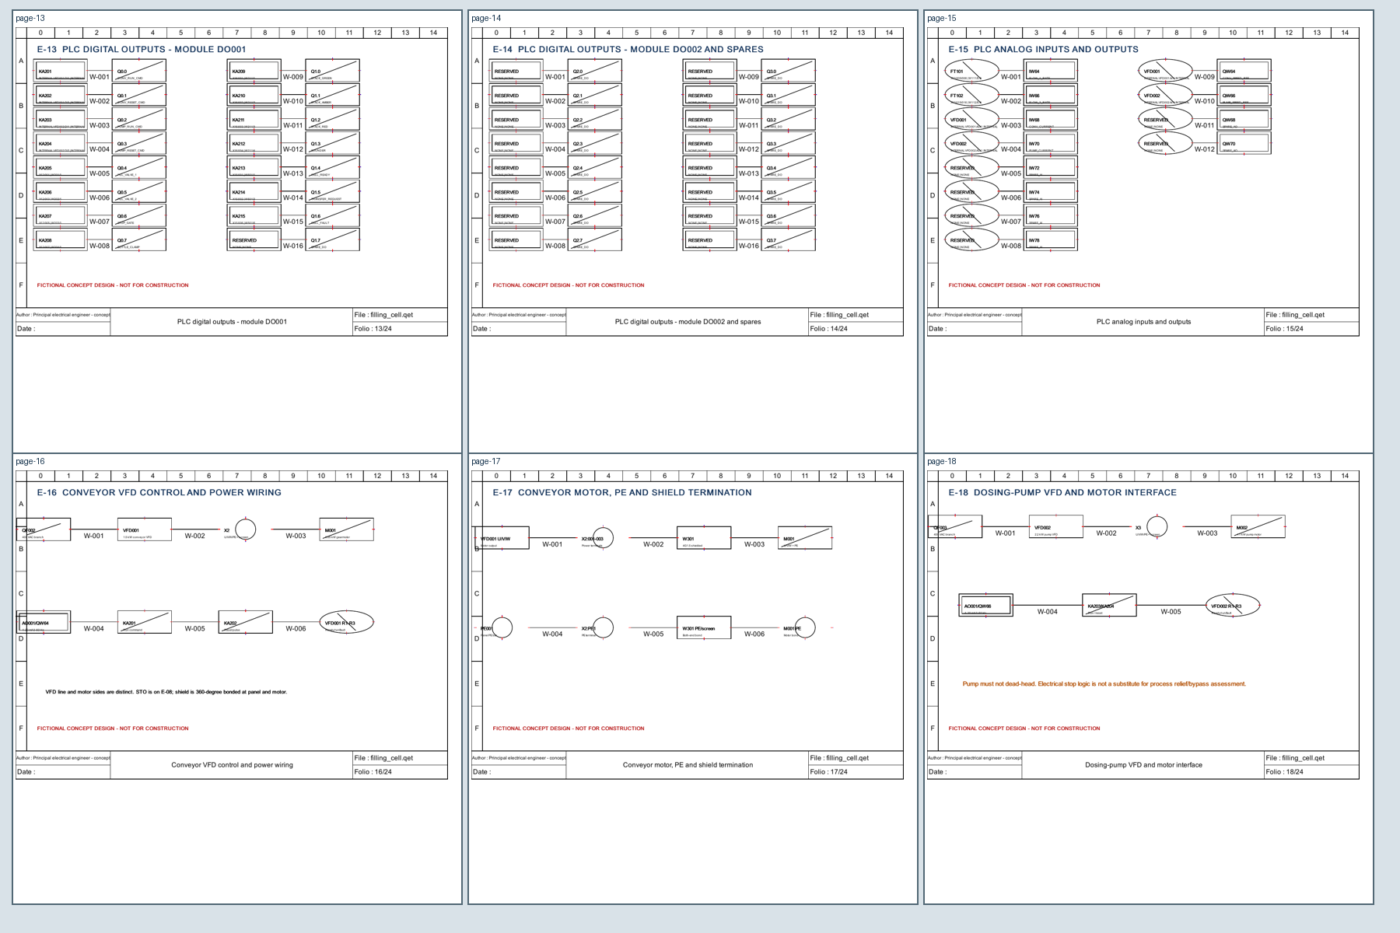
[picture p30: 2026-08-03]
14_qa/pdf_contact_sheets/qet-baseline-contact-03.png

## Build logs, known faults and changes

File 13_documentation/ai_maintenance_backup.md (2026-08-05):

# NVIDIA inspection maintenance, backup and rollback

> FICTIONAL ENGINEERING PROJECT — NOT FOR CONSTRUCTION

> CONCEPTUAL SAFETY ARCHITECTURE — REQUIRES PROJECT-SPECIFIC RISK ASSESSMENT, DESIGN, VERIFICATION AND VALIDATION BY A QUALIFIED MACHINERY-SAFETY ENGINEER. NO PERFORMANCE LEVEL, SIL, CATEGORY, CE CONFORMITY OR REGULATORY COMPLIANCE IS CLAIMED.

Maintain separate, hashed records for the OS/container image, edge-service package, configuration, node map, certificates/trust stores, camera settings, calibration, model bundle and dataset/model card. Private keys must be backed up only under the site key-management policy; they are not stored in this repository.

Routine inspection covers optics cleanliness, focus/aperture locks, lighting output/temperature, mount datum, cable/shield condition, storage capacity, time synchronization, certificate expiry, logged diagnostics, queue/latency trends and model/configuration identity. Any replacement or adjustment requires the controlled image-quality checklist and challenge set.

Deployment uses inactive-slot staging. Verify signature and SHA-256, run configuration and interface checks, switch during an approved window and retain the prior approved slot. Roll back on identity mismatch, startup/readiness failure, excessive latency, health degradation, challenge-set regression or unexplained quality shift. A rollback restores a known approved bundle but does not waive investigation, dataset review or optics verification.

THE NVIDIA VISION SUBSYSTEM IS NON-SAFETY-RELATED AND MUST NOT BE USED AS THE SOLE MEANS OF PERSONNEL PROTECTION, SAFE STOP, GUARD MONITORING OR HAZARDOUS-MOTION CONTROL.

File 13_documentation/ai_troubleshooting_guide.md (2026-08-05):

# NVIDIA inspection troubleshooting guide

> FICTIONAL ENGINEERING PROJECT — NOT FOR CONSTRUCTION

> CONCEPTUAL SAFETY ARCHITECTURE — REQUIRES PROJECT-SPECIFIC RISK ASSESSMENT, DESIGN, VERIFICATION AND VALIDATION BY A QUALIFIED MACHINERY-SAFETY ENGINEER. NO PERFORMANCE LEVEL, SIL, CATEGORY, CE CONFORMITY OR REGULATORY COMPLIANCE IS CLAIMED.

| Symptom | First checks | PLC disposition | Closure evidence |
|---|---|---|---|
| Vision not ready | Configuration signature, camera/model health, certificate trust, storage and time | HOLD; no transfer | Healthy startup log and controlled identity snapshot |
| Capture not acknowledged | Trigger identity, camera connection, exposure/trigger mode, queue depth | HOLD then fault at deadline | Correlated capture record |
| Low confidence | Optics cleanliness, glare, focus, bottle/liquid lot, lighting and threshold provenance | Operator disposition | Challenge-set rerun; do not lower threshold without approval |
| Wrong/stale/duplicate ID | Session epoch, restart/reconnect record and retained publication | Reject result; HOLD/FAULT | Exact transaction reconciliation |
| Model hash mismatch | Active bundle, configuration and rollback slot | FAULT | Approved signature/SHA and model card |
| Excessive latency | Input rate, queue, GPU/thermal/storage load and pipeline stages | HOLD | Representative target benchmark |
| OPC UA disconnect | Network/VLAN/firewall, certificates, endpoint and time | FAULT; preserve current product | Secure reconnect and disabled synchronization |
| Log storage failure | Capacity, permissions, media health and retention service | FAULT | Durable audit write and recovery test |

Do not bypass quality or change model/threshold/calibration values as a troubleshooting shortcut. The HMI maintenance mode provides diagnostics and controlled disposition only; it cannot bypass PLC interlocks or safety functions.

THE NVIDIA VISION SUBSYSTEM IS NON-SAFETY-RELATED AND MUST NOT BE USED AS THE SOLE MEANS OF PERSONNEL PROTECTION, SAFE STOP, GUARD MONITORING OR HAZARDOUS-MOTION CONTROL.

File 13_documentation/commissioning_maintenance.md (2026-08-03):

# Commissioning and maintenance manual

> FICTIONAL ENGINEERING PROJECT — NOT FOR CONSTRUCTION

> CONCEPTUAL SAFETY ARCHITECTURE — REQUIRES PROJECT-SPECIFIC RISK ASSESSMENT, DESIGN, VERIFICATION AND VALIDATION BY A QUALIFIED MACHINERY-SAFETY ENGINEER. NO PERFORMANCE LEVEL, SIL, CATEGORY, CE CONFORMITY OR REGULATORY COMPLIANCE IS CLAIMED.

## Commissioning stages

1. Approve documents, open issues and qualified safety work.
2. Perform de-energized construction inspection, PE continuity and torque verification.
3. Energize by branch with approved instruments and temporary controls.
4. Execute point-to-point I/O checkout, drive rotation, actuator dry tests and fault injection.
5. Perform wet calibration, flowmeter comparison, recipe tuning and leakage/closure tests.
6. Complete optical calibration, real-product challenge testing and capper integration.
7. Compile/archive/backup, train users and obtain signed FAT/SAT deviations.

## Preventive tasks

Maintain terminal torque per manufacturer, filters/fans, earth/shield bonds, valve leakage, flowmeter calibration, camera/lights/optics, drive faults and model/certificate versions. Energy isolation and external safety procedures are site responsibilities.

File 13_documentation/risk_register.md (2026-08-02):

# Risk and limitation register

> FICTIONAL ENGINEERING PROJECT — NOT FOR CONSTRUCTION

> CONCEPTUAL SAFETY ARCHITECTURE — REQUIRES PROJECT-SPECIFIC RISK ASSESSMENT, DESIGN, VERIFICATION AND VALIDATION BY A QUALIFIED MACHINERY-SAFETY ENGINEER. NO PERFORMANCE LEVEL, SIL, CATEGORY, CE CONFORMITY OR REGULATORY COMPLIANCE IS CLAIMED.

Key open risks are unintended assumptions about utilities/motors; incomplete native Siemens verification; stale/uncertain vision results; optical domain shift; incorrect field continuity; inadequate thermal/EMC/protection data; unauthorized changes; and confusion between conceptual safety monitoring and safety control. Controls are documented holds, native gates, independent review, change control and qualified project-specific engineering.

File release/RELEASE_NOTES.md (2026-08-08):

# Revision G release notes

> FICTIONAL ENGINEERING PROJECT - NOT FOR CONSTRUCTION.

> CONCEPTUAL SAFETY ARCHITECTURE - REQUIRES PROJECT-SPECIFIC RISK ASSESSMENT, DESIGN, VERIFICATION AND VALIDATION BY A QUALIFIED MACHINERY-SAFETY ENGINEER. NO PERFORMANCE LEVEL, SIL, CATEGORY, CE/UKCA CONFORMITY OR REGULATORY COMPLIANCE IS CLAIMED.

Revision G adds a secure, disabled-by-default Google Cloud foundation; exact installed Siemens/NVIDIA inventories and closure handoffs; official-current DeepStream 9.1 planning; a data-gated container/training/evaluation package with deterministic synthetic fail-closed smoke; and controlled blank commissioning/qualified-review records. It does not create cloud resources, a native TIA project, a model, model metrics, physical evidence or professional approval.

THE NVIDIA VISION SUBSYSTEM IS NON-SAFETY-RELATED AND MUST NOT BE USED AS THE SOLE MEANS OF PERSONNEL PROTECTION, SAFE STOP, GUARD MONITORING OR HAZARDOUS-MOTION CONTROL.

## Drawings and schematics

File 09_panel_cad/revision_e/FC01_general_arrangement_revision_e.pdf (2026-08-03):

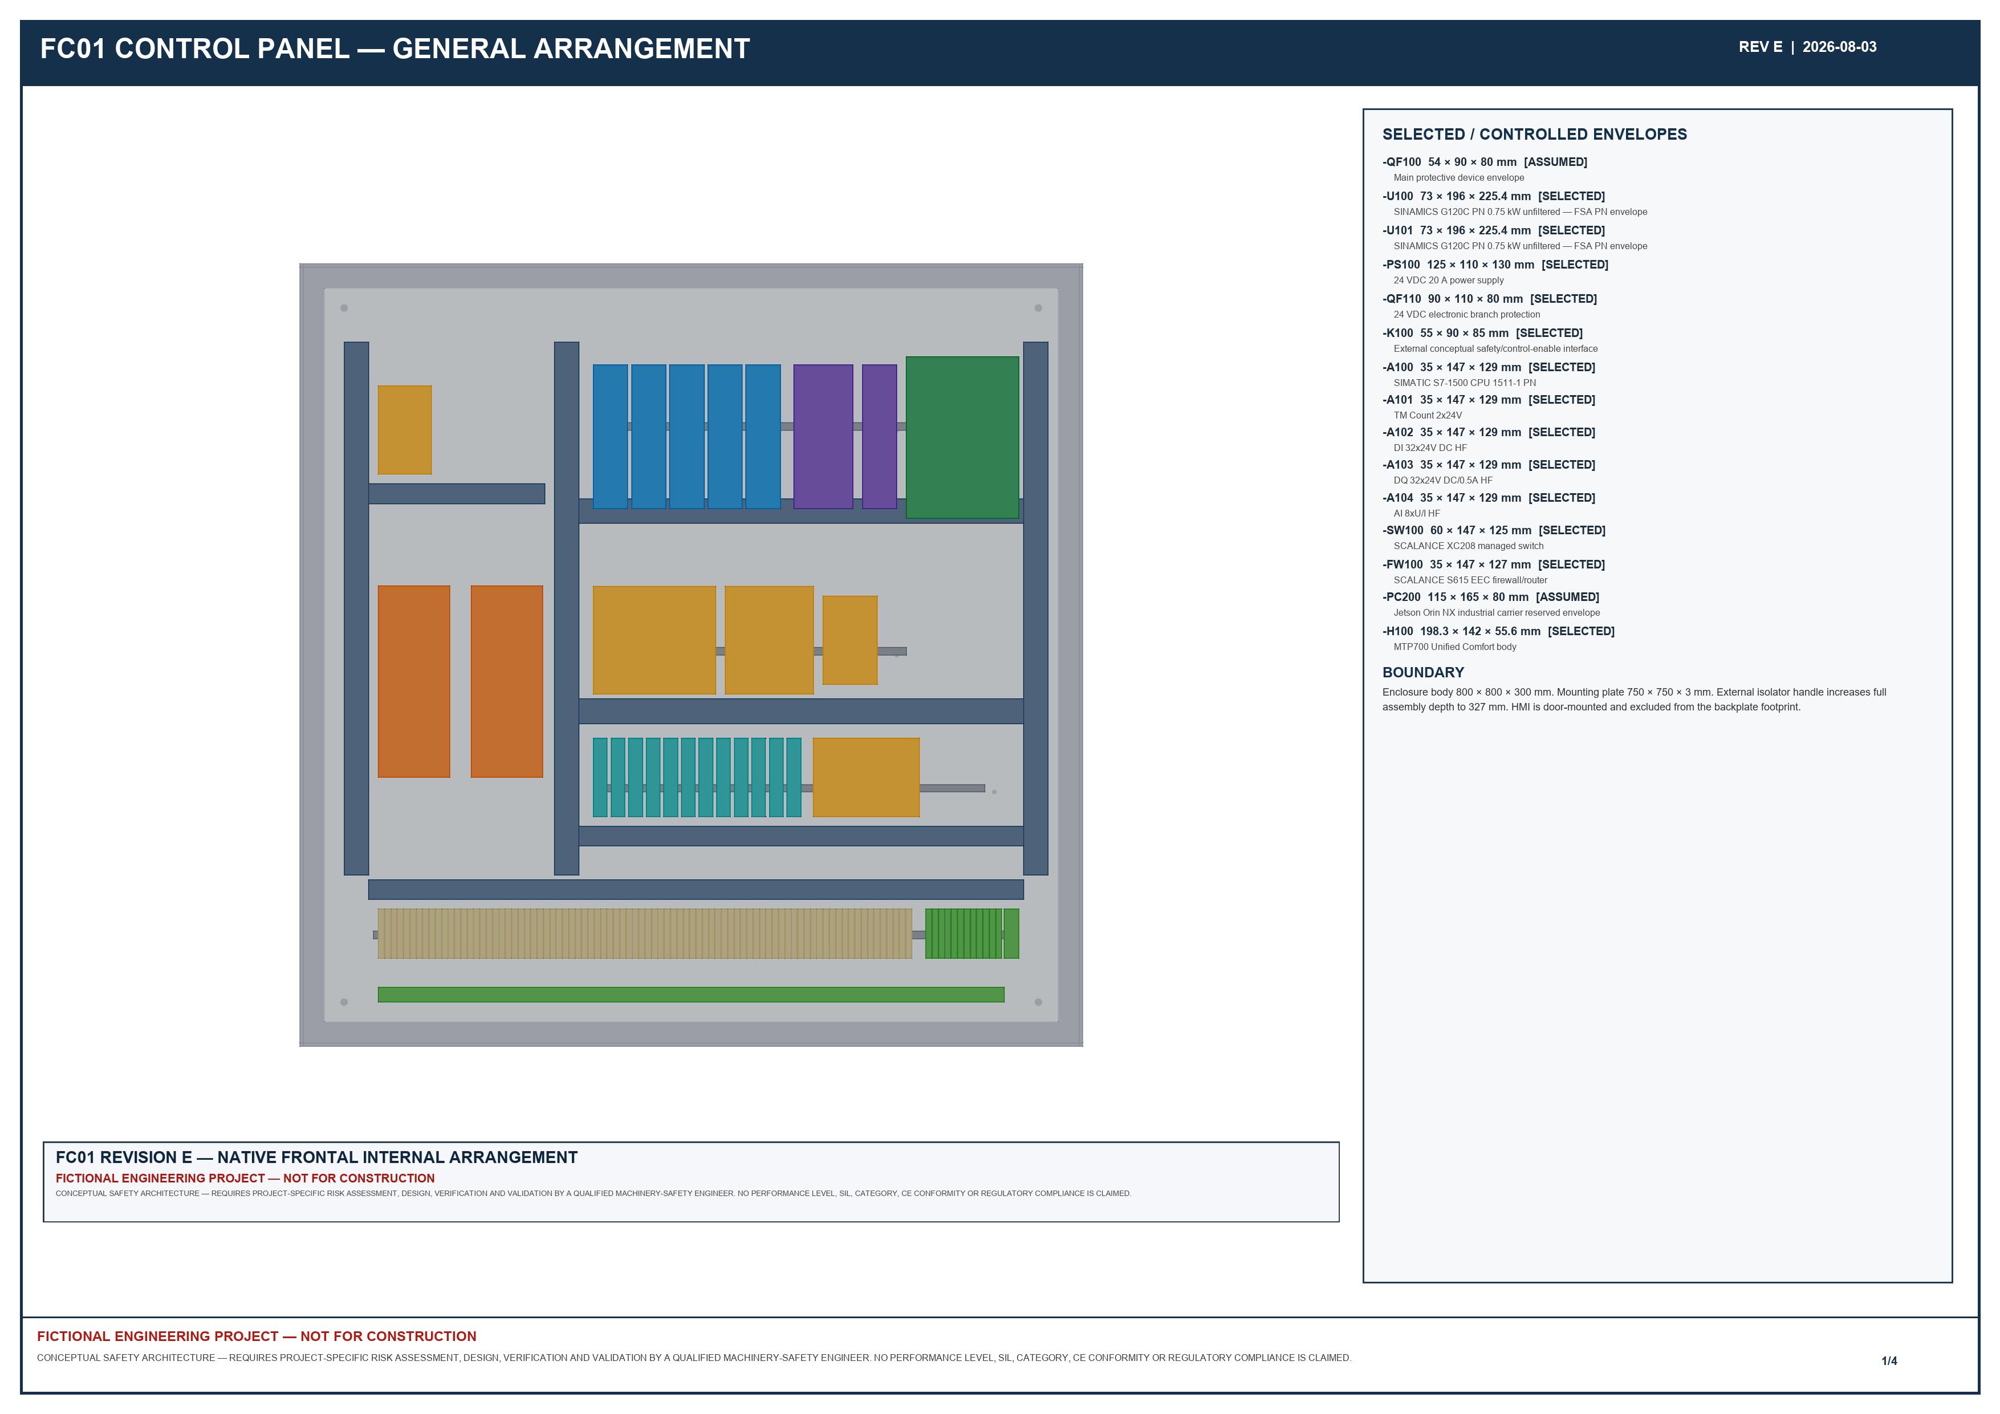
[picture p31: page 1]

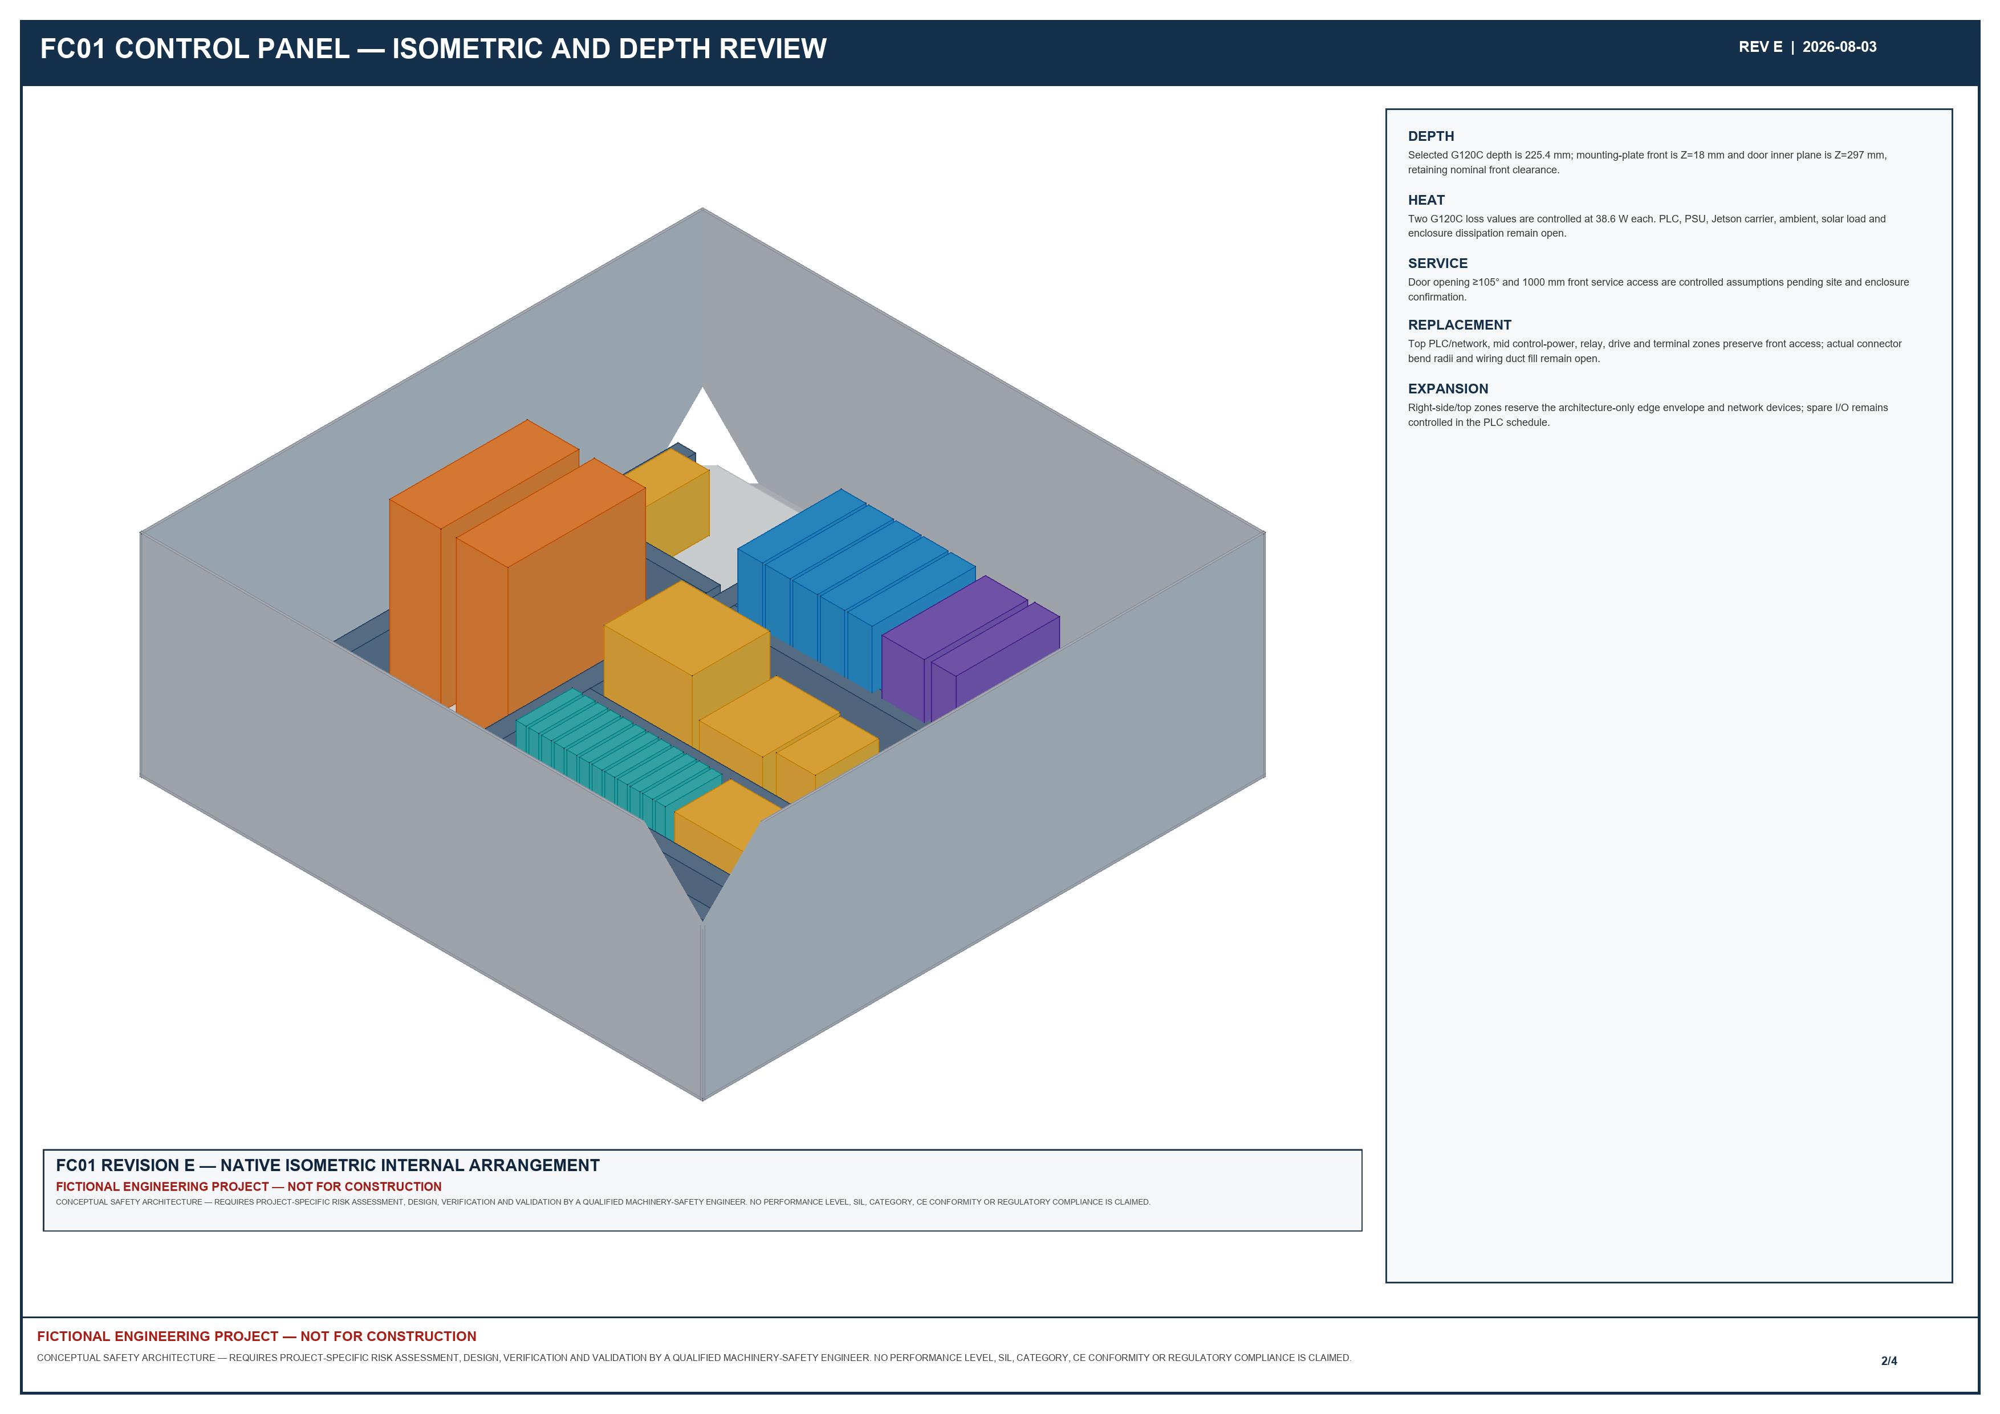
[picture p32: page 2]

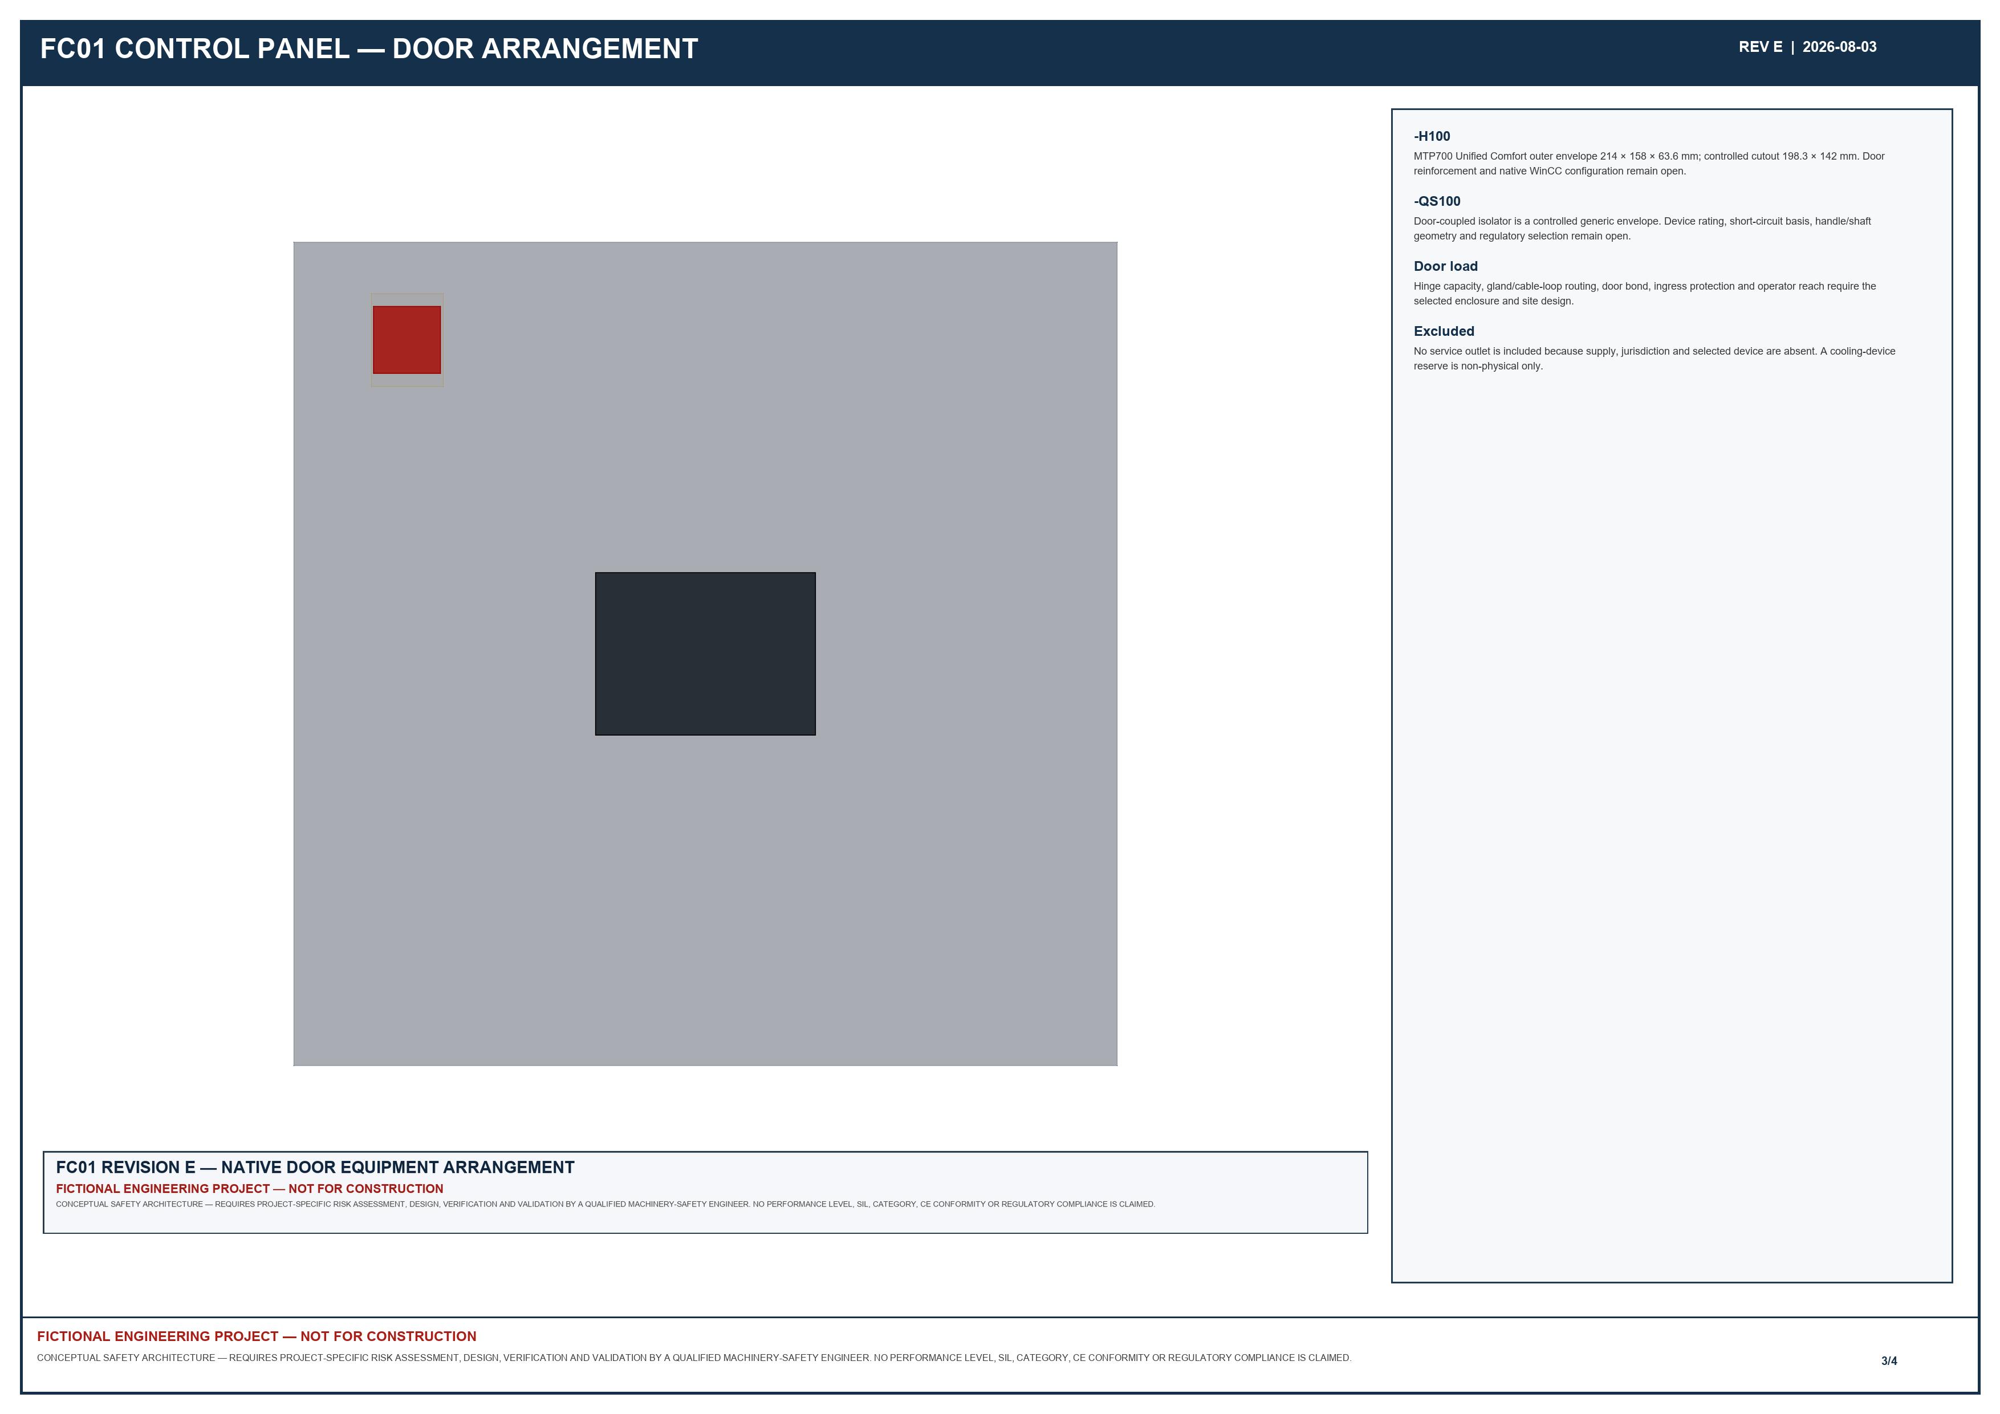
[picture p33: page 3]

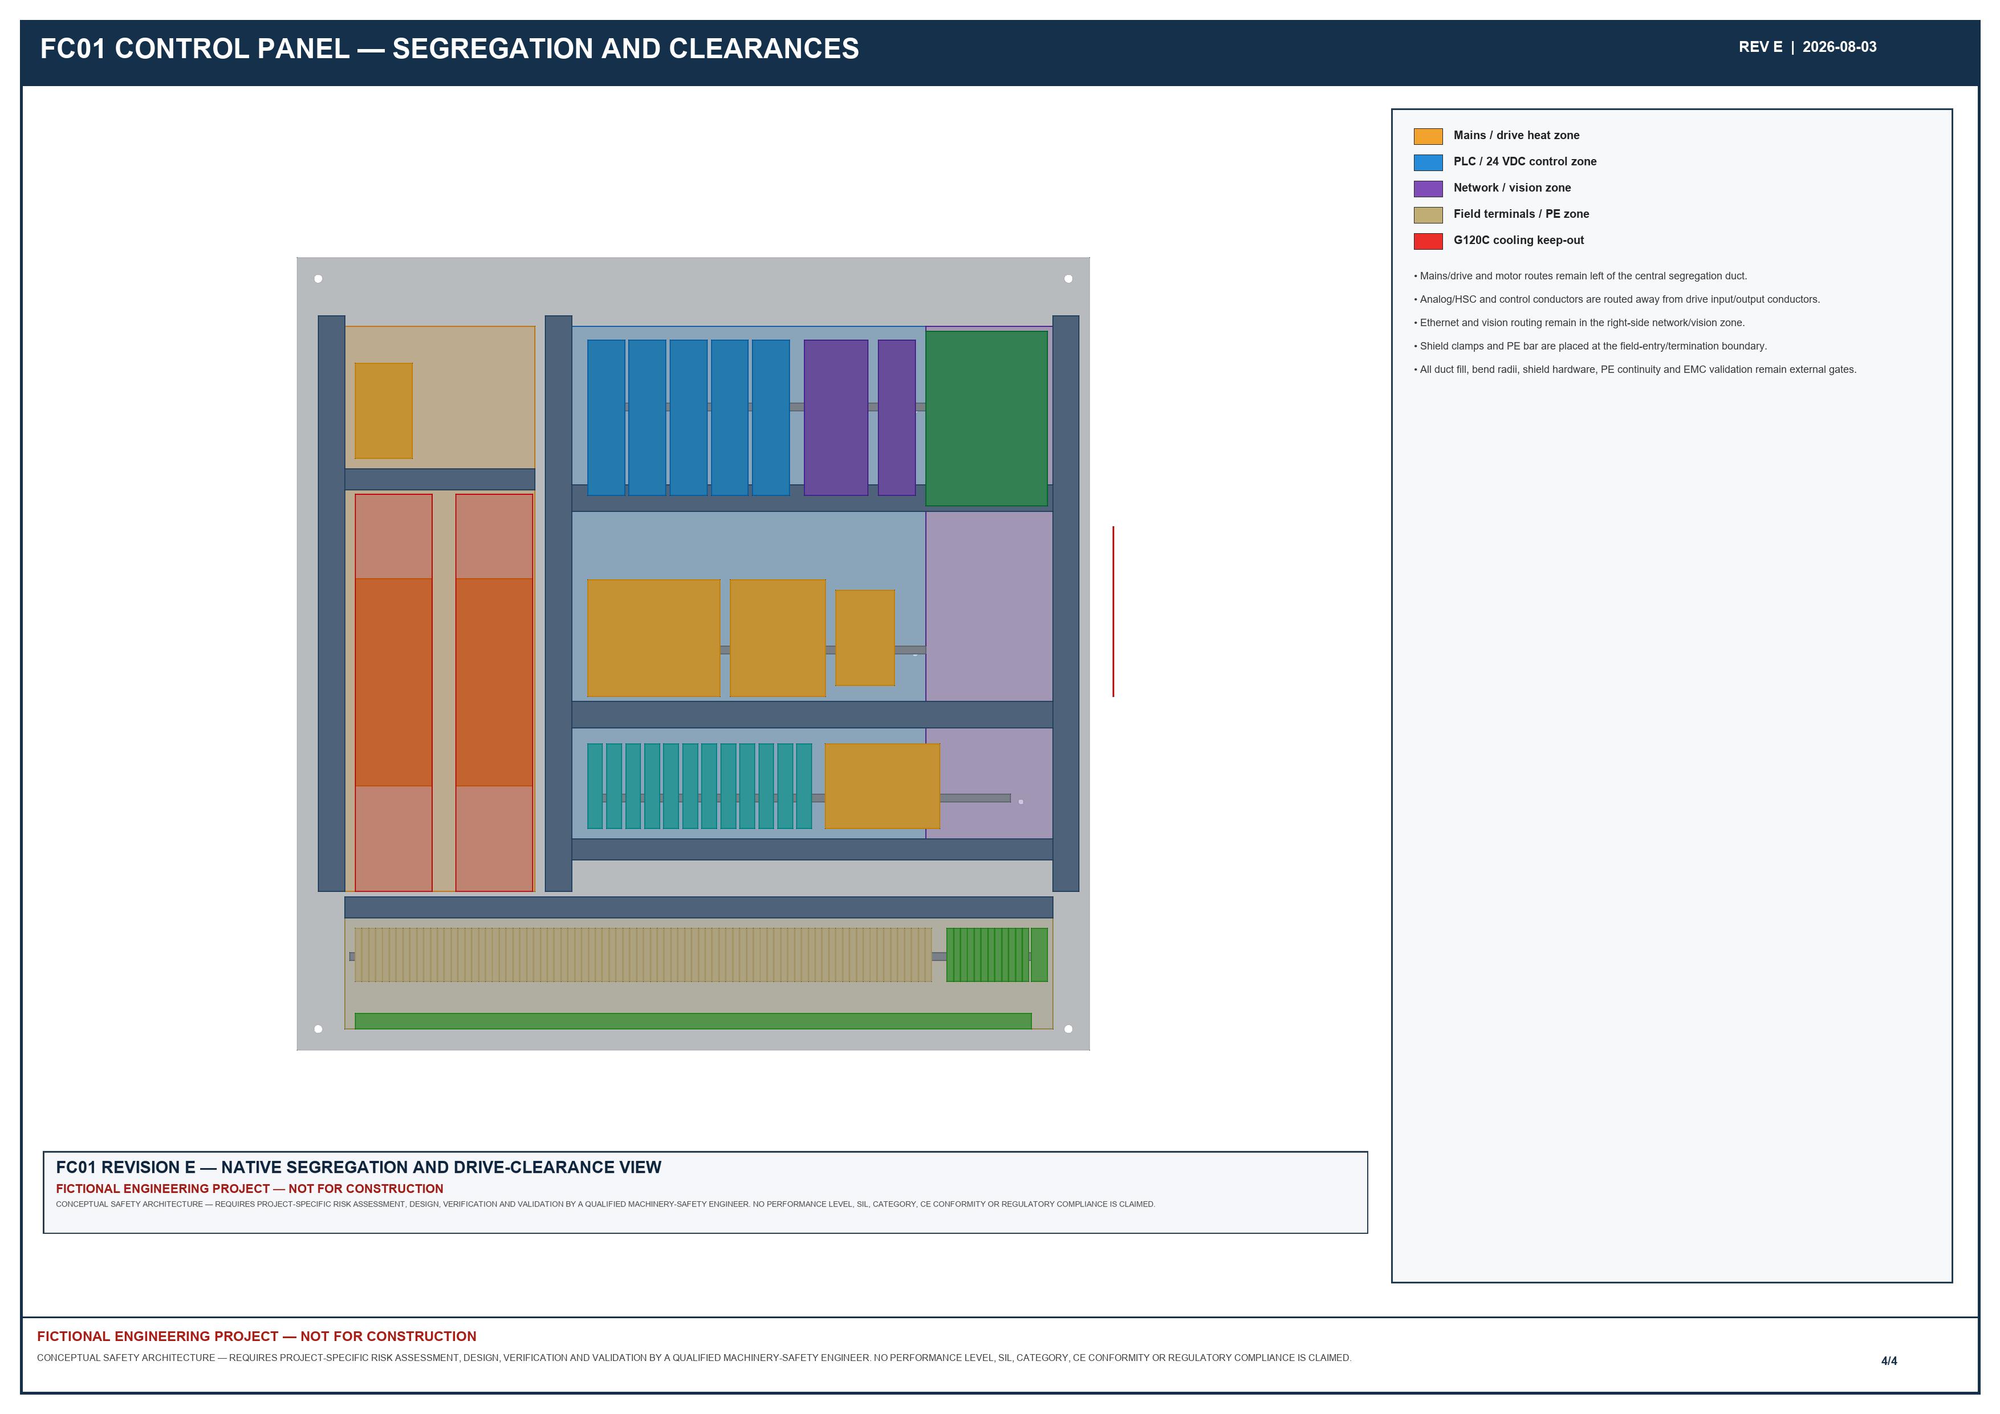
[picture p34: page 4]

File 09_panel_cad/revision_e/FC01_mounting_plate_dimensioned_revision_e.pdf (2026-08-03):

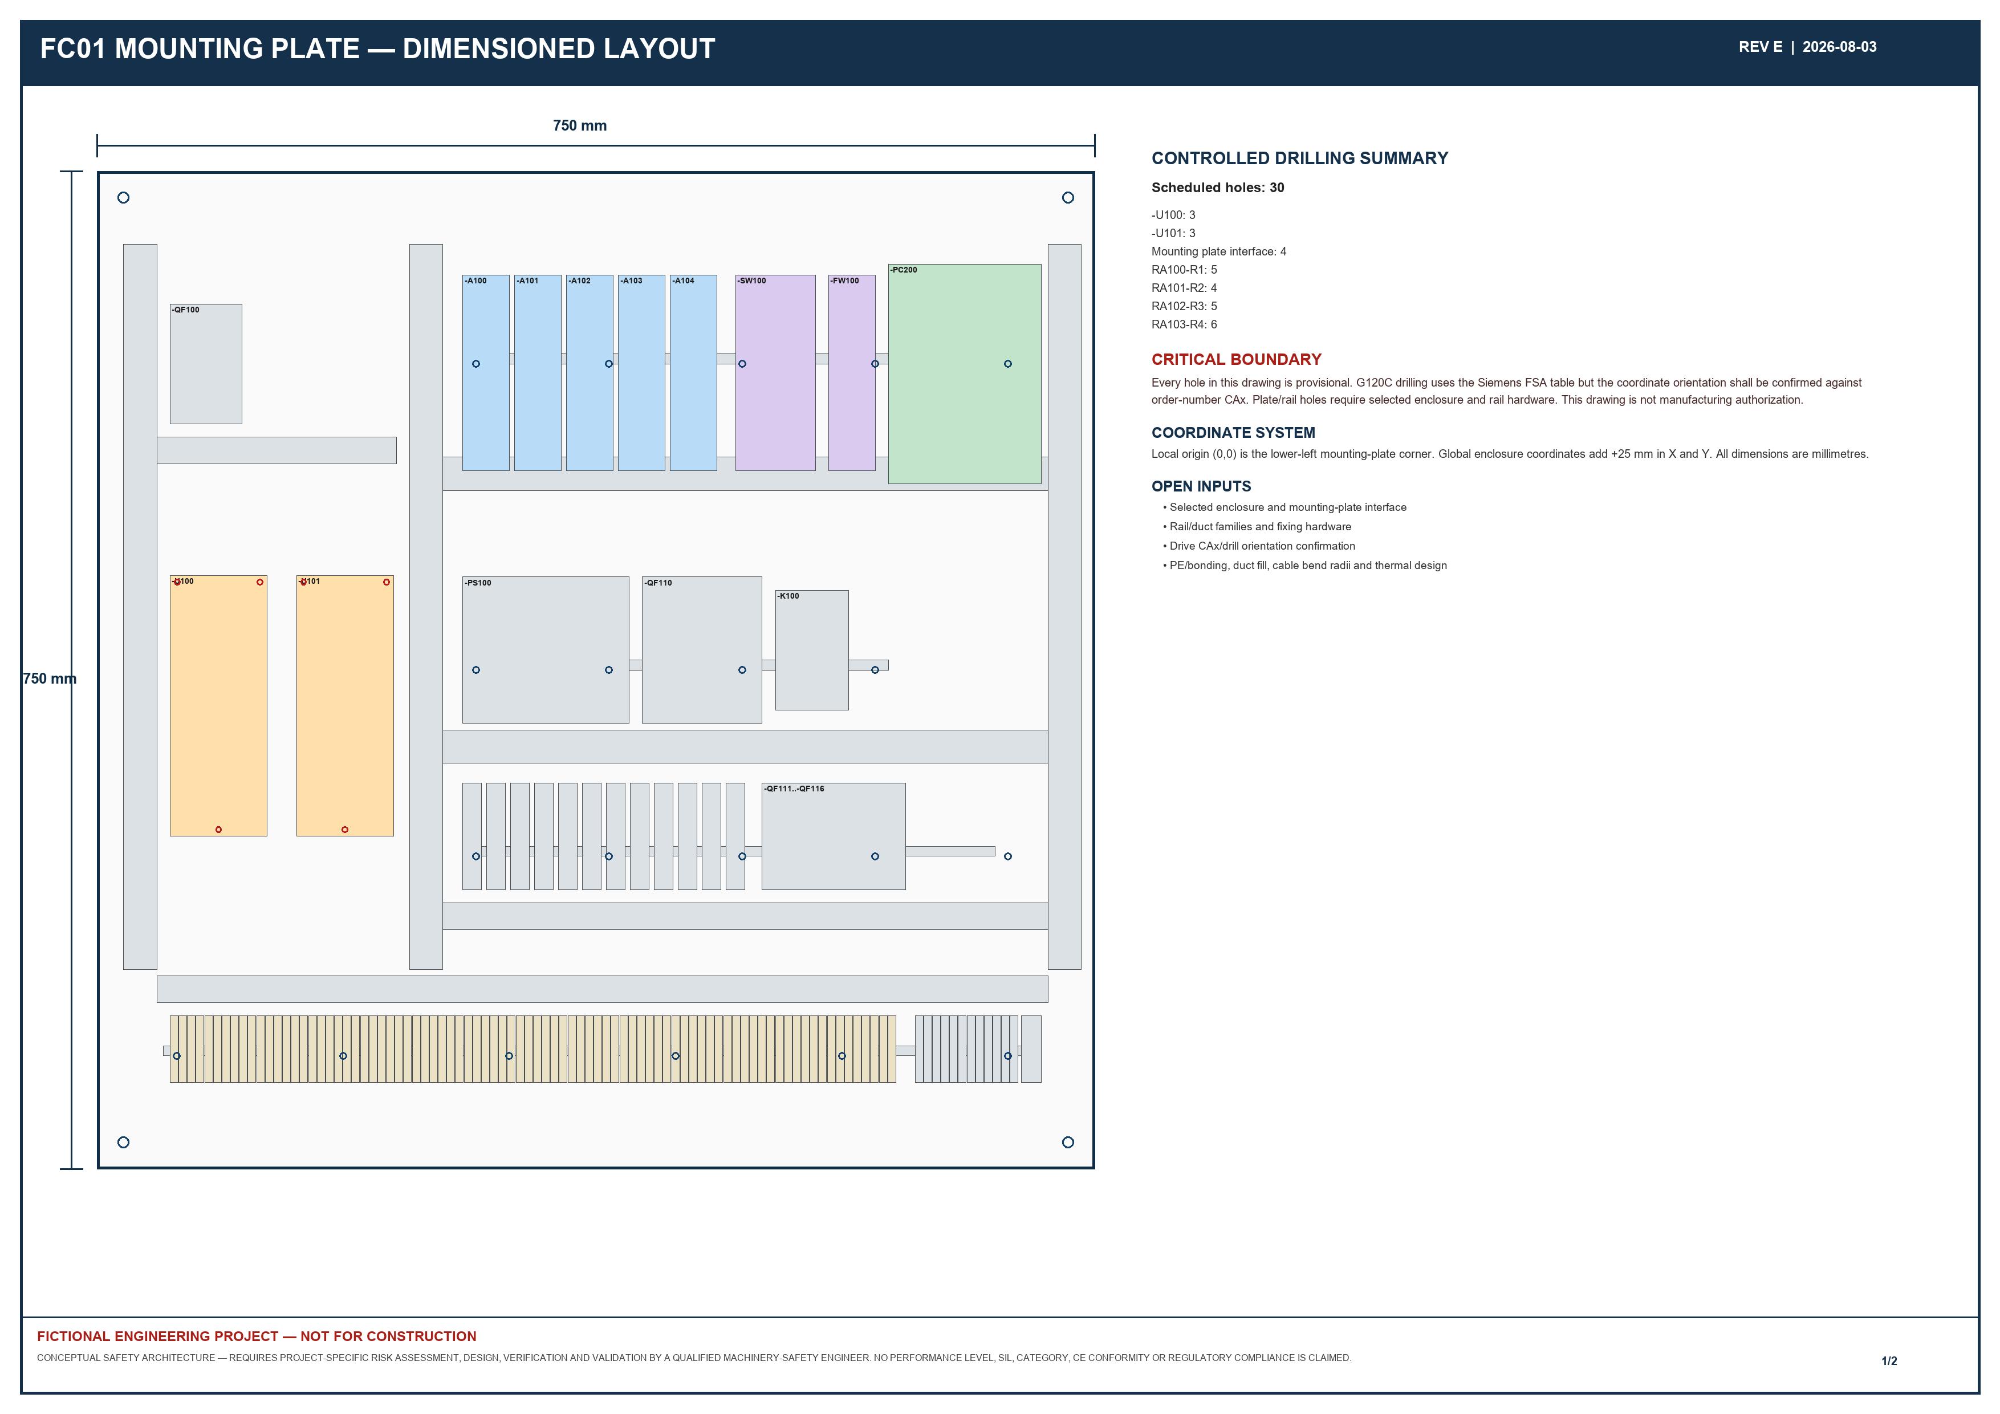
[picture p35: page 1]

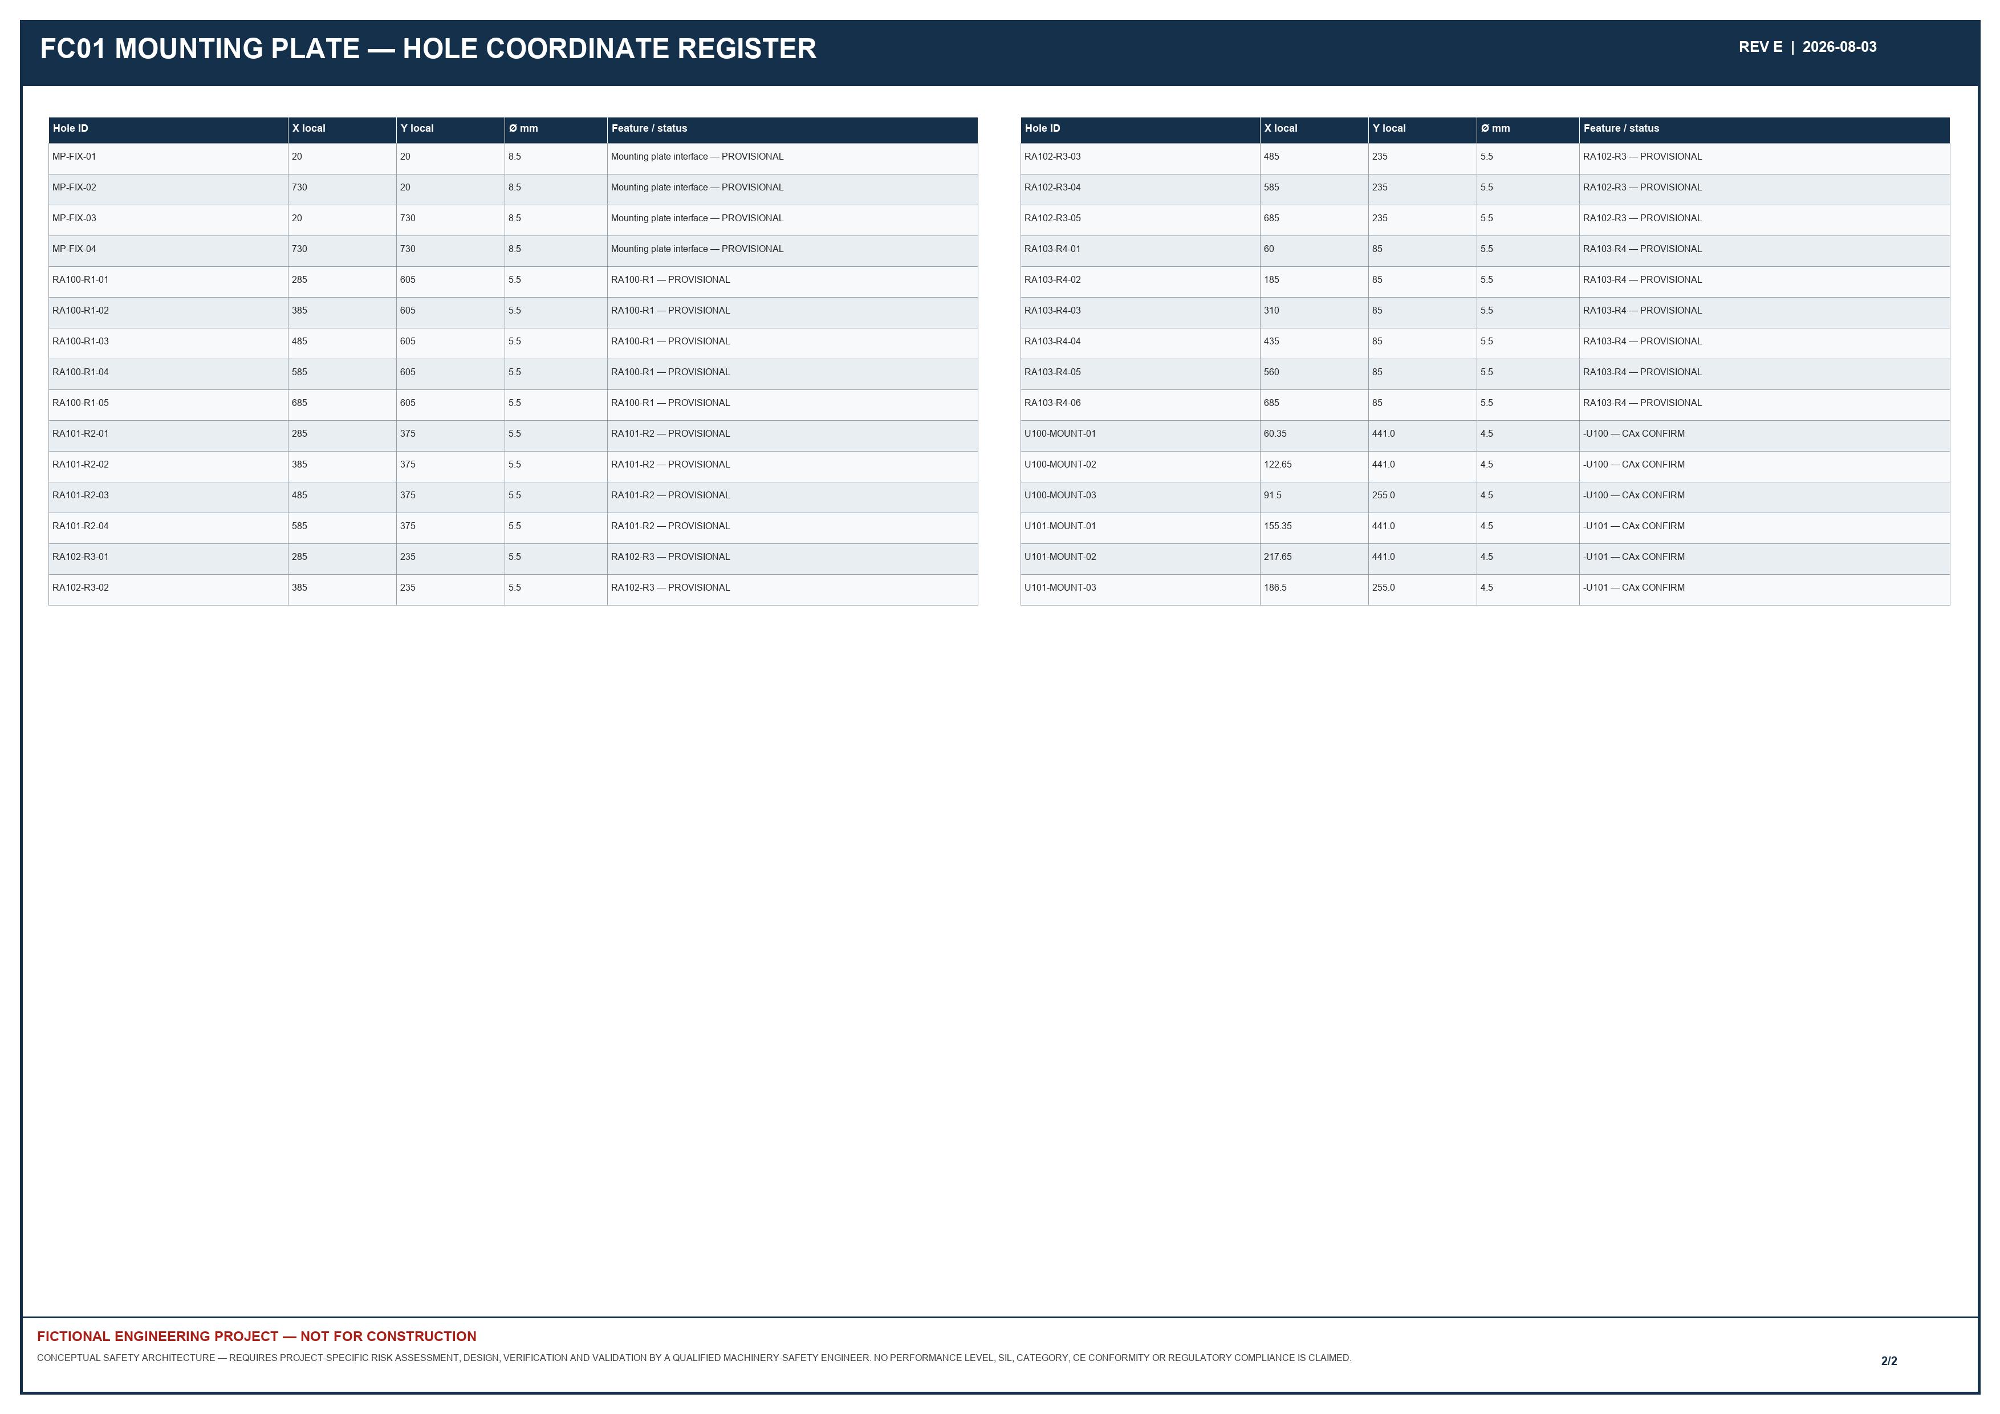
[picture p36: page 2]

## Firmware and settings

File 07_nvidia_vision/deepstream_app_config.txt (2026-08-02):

# FICTIONAL ENGINEERING PROJECT — NOT FOR CONSTRUCTION
# DeepStream 9.1 design configuration; syntax/runtime validation blocked because DeepStream is not installed.
[application]
enable-perf-measurement=1
perf-measurement-interval-sec=5
[source0]
enable=1
type=1
camera-width=1920
camera-height=1200
camera-fps-n=30
camera-fps-d=1
[streammux]
batch-size=1
width=1920
height=1200
batched-push-timeout=40000
[primary-gie]
enable=1
model-engine-file=MODEL_NOT_DELIVERED.engine
config-file=config_infer_primary.txt
batch-size=1
[sink0]
enable=1
type=1
sync=0

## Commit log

2026-08-02 Initial Siemens NVIDIA filling cell engineering package
    [FC01_engineering_schedules.xlsx, agent_ownership.csv, alarms.csv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]
2026-08-02 Revision C industry completion package
    [FC01_engineering_schedules.xlsx, acceptance_gates.csv, air_pressure_loss.csv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]
2026-08-02 Revision D engineering hardening and deterministic release
    [FC01_engineering_schedules.xlsx, acceptance_gates.csv, agent_ownership.csv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]
2026-08-03 Harden Revision D.1 release and control contracts
    [acceptance_gates.csv, agent_ownership.csv, alarms.csv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]
2026-08-03 Freeze Revision D.1 release evidence and manifest
    [FC01_engineering_schedules.xlsx, air_pressure_loss.csv, both_bottles_missing.csv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]
2026-08-03 Make determinism evidence identical for index and HEAD
    [manifest.csv, review_records.csv]
2026-08-03 feat: execute Revision E native engineering
    [FC01_control_panel_revision_e.FCStd, FC01_control_panel_revision_e.iges, FC01_control_panel_revision_e.step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]
2026-08-03 chore: freeze Revision E release manifest
    [manifest.csv]
2026-08-03 docs: record Revision E clean-clone release evidence
    [FC01_engineering_schedules.xlsx, acceptance_gates.csv, document_register.csv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]
2026-08-03 chore: attest final Revision E manifest
    [manifest.csv]
2026-08-03 chore: refresh final Revision E manifest
    [manifest.csv]
2026-08-04 feat: deliver Revision F NVIDIA readiness package
    [FC01_engineering_schedules.xlsx, acceptance_gates.csv, component_rationale.csv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]
2026-08-04 fix: harden Revision F clean-clone reliability
    [FC01_engineering_schedules.xlsx, manifest.csv, requirements_traceability.csv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]
2026-08-04 fix: isolate FreeCAD verification caches
    [manifest.csv, review_records.csv]
2026-08-04 fix: normalize Revision F behavioral evidence
    [manifest.csv, review_records.csv]
2026-08-04 fix: close Revision F workbook render reproducibility
    [decision_register.csv, engineering_change_register.csv, manifest.csv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]
2026-08-04 chore: attest Revision F clean-clone release
    [FC01_engineering_schedules.xlsx, acceptance_gates.csv, manifest.csv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]
2026-08-05 fix: remove attestation manifest self-reference
    [manifest.csv, review_records.csv]
2026-08-08 feat: establish Revision G native cloud execution package
    [FC01_engineering_schedules.xlsx, acceptance_gates.csv, as_built_redline_register.csv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]
2026-08-08 fix: stabilize Revision G generated QA evidence
    [manifest.csv]
2026-08-08 docs: attest Revision G published-candidate reproduction
    [FC01_engineering_schedules.xlsx, acceptance_gates.csv, document_register.csv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]
